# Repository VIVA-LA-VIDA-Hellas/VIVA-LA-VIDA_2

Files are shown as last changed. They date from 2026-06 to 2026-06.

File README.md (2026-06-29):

# **VIVA ΛA VIΔA** 
# $${\color{green}FUTURE \space ENGINEERS \space 2025}$$ 
> ## HELLENIC TEAM

viva la vida gif

## <ins>*Find us on:*<ins/>
Website (https://www.viva-la-vida.gr/)
Youtube (https://www.youtube.com/@VIVALAVIDAFutureEnginners)
Facebook (https://www.facebook.com/groups/1252558666360750)
Instagram (https://www.instagram.com/viva_la_vida_gr/)
TikTok (https://www.tiktok.com/@viva_la_vida_gr)

## TEAM MEMBERS:
### Giannis Kapanikis (user: Dante1307)
### Panagiotis Mourmouris (user: Panos1431)
### Thanos Karatsis (user: thkaratsis)

# INDEX
### *Use the index for an easy navigation of our github or, continue bellow to view our creation process, as well as an overview on everything about the robot.*

## 1. Mobility management
####        1.1 [Motor](schemes/Mechanical_Parts/Motor)
####        1.2 [Ackerman](schemes/Mechanical_Parts/Ackermann)
####        1.3 [Servo](schemes/Mechanical_Parts/Servo)
####        1.4 [Servo and motor 3d Bases](models/3d_designs)

## 2. Power Management
####        2.1 [PCB circuit designs and schematics](schemes/PCB_Design)

## 3. Sensors
####        2.1 [Distance sensors](schemes/Sensors/Distance_Sensors)
####        2.2 [Accelerometre / Gyro](schemes/Sensors/Accelerometre_Gyro)
####        2.3 [Camera](schemes/Sensors/Camera)
####        2.4 [Buttons & Leds](schemes/Sensors/Buttons_Leds)

## 4. 3D Prints
####        4.1 [3D schematics](models/3d_designs)

## 5. Pictures 
####        5.1 [Team photos](t-photos)
####        5.2 [Vehicle photographs](v-photos)

## 6. Performance videos
####        6.1 [Youtube channel link](https://www.youtube.com/@VIVALAVIDAFutureEnginners)
####        6.2 [All video links](video)

## 7. Code files
####        8.1 [Open Challenge](src/1.Open_Challenge)
####        8.2 [Obstacle Challenge](src/2.Obstacle_Challenge)
####        8.3 [Colour Calibration](other/python_files/Color_Picker.py)

## 8. Manuals
####        9.1 [Instruction manuals](schemes/instructions)
####        9.2 [Lego ackerman instructions](schemes/instructions/lego_ackermann_instructions.md)
####        9.3 [Lego differential instructions](schemes/instructions/lego_differential_instructions.md)
####        9.4 [Build details](v-photos)
####        9.5 [Full instructions](schemes/instructions/Instruction_manuals.md)

## 9. Extra material
####        10.1 [Team logo](https://github.com/VIVA-LA-VIDA-Hellas/VIVA-LA-VIDA/tree/main/Team%20-%20Extras/Logo)
####        10.2 [Team name - VIVA ΛΑ VIΔΑ](https://github.com/VIVA-LA-VIDA-Hellas/VIVA-LA-VIDA/tree/main/Team%20-%20Extras/Name)
####        10.3 [Team shirts](https://github.com/VIVA-LA-VIDA-Hellas/VIVA-LA-VIDA/tree/main/Team%20-%20Extras/Shirts)

# RESEARCH / EXPERIMENTAL PHASE

### Creating [red/green colour detection](https://github.com/VIVA-LA-VIDA-Hellas/VIVA-LA-VIDA/blob/main/Code%20files/Python%20files/R_G_cannyoutlineWORKING.py)
Using python and opencv we created a program that detects red and green objects and outputs what the computer sees in the prossess.
To do this, firstly we used colour dropping to <ins> find approximate HSV values  of obstacles and edit the ranges in our code </ins>

### $${\color{red}Red:}$$



### $${\color{green}Green:}$$



### [Colour picker used](https://pinetools.com/image-color-picker)

Using the data, we created a range where an object is detected as red or green. The full range that can be detected is min:0 , max:255
```python
    red_lower = np.array([0, 120, 70])
    red_upper = np.array([10, 255, 255])
```
```python
    green_lower = np.array([45, 160, 0])
    green_upper = np.array([100, 255, 150])
```
Then, we applied a HSV mask to separate the objects of each colour from the rest of the feed and used imgcanny to find the corners of the objects detected, using that to add an outline according to their colour (red/green)
Mask:
```python
mask_red1 = cv2.inRange(imgHSV, red_lower, red_upper)
```
Outline:
```python
    img_contours = img.copy()
    for contour in contours_red:
        x, y, w, h = cv2.boundingRect(contour)
        cv2.rectangle(img_contours, (x, y), (x + w, y + h), (0, 0, 255), 2)  # Red rectangle
```
Same for green.
> ### Green:


> ### Red:



Notice how it even detects the pile of red objects on the floor **~3m away**, We want to turn based on the closest object to the robot at any given time.
To detect that, we add limits to the size we consider an object 
> We do this so that it doesnt start turning too early or if it sees a spec of green/red in the background), its basically a filtering process that cuts down on most of the >noise.

For trials we set the minimum requirement in size (area) for a detected colour mass to be considered an object, as **500 pixels**
```python
def get_largest_contour(mask, min_area=500)
```

Next, we made it choose the largest object visible to focus on first
```python
def get_largest_contour(mask, min_area=500):
    contours, _ = cv2.findContours(mask, cv2.RETR_EXTERNAL, cv2.CHAIN_APPROX_SIMPLE)
    if not contours: return None
    largest = max(contours, key=cv2.contourArea)
    if cv2.contourArea(largest) < min_area: return None
    x, y, w, h = cv2.boundingRect(largest)
    return largest, (x, y), (x + w, y + h), w*h
```

### Updating our colour picking method
The issue with this code was that it needed calibrating in different lighting conditions, so we made out own [colour picker](https://github.com/VIVA-LA-VIDA-Hellas/VIVA-LA-VIDA/blob/main/Code%20files/Python%20files/New%20files%20September%2B/Colour_picker.py) that worked more accurately with the hsv values our camera detected. With this the obstacle detection became much more time efficient but also accurate.

Colour picker sample
```python
def mouse_callback(event, x, y, flags, param):
    global frame
    if event == cv2.EVENT_LBUTTONDOWN and frame is not None:
        bgr = frame[y, x]
        hsv = cv2.cvtColor(np.uint8([[bgr]]), cv2.COLOR_BGR2HSV)[0][0]
        print(f"Clicked at ({x},{y}) | BGR: {bgr} | HSV: {hsv}")

cv2.namedWindow("Live Feed")
cv2.setMouseCallback("Live Feed", mouse_callback)
```
We use input from our camera to our computer as a live feed, clicking on any pixel to get the HSV values the camera detects straight to our terminal.
We can then imput them straight into our colour detection limits, (red_lower, red_upper, green_lower, green_upper)

### Using what we detected to avoid the obstacles
Now that we can succesfully detect the red and green obstacles, we decided to implement a simple system for the robot to use in order to turn. 
It uses the Objects detected as a reference point and tries to rotate away from them, untill they are outside of the visible area (in other words, when they are far away enough for the robot to not collide with them).
Reminder, the robot must move **right** if it detects **red** and on the flip side, **left** when it detects **green**
> In other words, if we draw a line on the right side of the "turn right" block (red) and the left side of the "turn left" block (green), by moving toward the side it is placed on and effectively moving the entire obstacle out of our view, we manage to pass it.

So for **Green** (Turn left):

green pillar

And for **Right** (Turn right):

red pillar

### Next, we created the [Middle_Lane_Canny](https://github.com/VIVA-LA-VIDA-Hellas/VIVA-LA-VIDA/blob/main/Code%20files/Python%20files/Middle_Lane_Canny_WORKING.py)
We applied the same code from the previous program, this time switching green and red with white and black in order to diffrentiate the (white) floor from the (black) walls.
From this process, instead of outlining the walls found, we used the line they formed from edge detection on each side and <ins> calculated the middle point between the two to create a path for the robot to follow </ins>
```python
for i in range(height):
        left_avg = left_edges[i]
        right_avg = right_edges[i]

        if left_avg is not None and right_avg is not None:
            # Calculate the midpoint and draw the path
            middle_line = (left_avg + right_avg) // 2

            # Draw the path line (white) with increased thickness
            cv2.line(edges_black, (middle_line, i), (middle_line, i), (255, 255, 255), 3)  # Increased thickness
```

[You can see the output we got here](https://github.com/VIVA-LA-VIDA-Hellas/VIVA-LA-VIDA/blob/main/Videos/MIDDLE_LANE_VIDEO_COMPRESSED.mp4)

### Output image

### When we moved the inner square walls, <ins>the path to follow (middle lane) moved too</ins>


### Why we didn't end up using this code (Middle_Lane_Canny) for the first mission
Although this code worked exceptionally well when the robot was faced with long straight paths surrounded by contrasting walls, the same can't be said for turns.
When we tested it with a large camera connected to a laptop, it was facing the track from a very high up angle so it had a better view and could detect turns well.
But, when we tested multiple different cameras connected to a raspberry pi, including a fisheye camera, none of them has a scope wide enough for the current code to predict sharp turns, so the path ended up either guiding the robot straight into the wall, or, turning the opposite direction than expected.  

This wasnt working for us. The camera couldn't be as high up as it was originally when its placed on the robot -in the track- and it also needed the robot to go relatively slow so it can catch up with the camera feedback. This is fine for the second mission, where obstacle avoidance is a higher priority than speed, but for a quick first mission we had to find a new way to sense when and how much the car needs to turn.

>[!NOTE]
>The fact that this detection process didn't work for us doesn't render it unuseable. Combined with the use of a different logic specifically for turns, there is potential for a useable output but we decided to take a different approach.

### Recognising turns - Detecting Blue and Orange lines
Using the same colour picking process we created earlier, we can also detect blue and orange. Using these colours we were able to turn as well as the direction of said turn.

Example values:
## $${\color{blue}Blue}$$
```python
    blue_lower = np.array([100, 60, 80])
    blue_upper = np.array([120, 120, 170])
    mask_blue = cv2.inRange(imgHSV, blue_lower, blue_upper)
```
## $${\color{orange}Orange}$$
```python
    orange_lower = np.array([0, 110, 110])
    orange_upper = np.array([20, 160, 230])
    mask_orange = cv2.inRange(imgHSV, orange_lower, orange_upper)
```

Of course, these values have to be calibrated before the launch of every mission due to the changes in lighting conditions, but we found that this process was much more failproof so it was utilised for the second mission.

The logic of the [Blue and Orange turn detection](https://github.com/VIVA-LA-VIDA-Hellas/VIVA-LA-VIDA/blob/main/Code%20files/Python%20files/New%20files%20September%2B/Stage%202/Orange%20Blue%20detection.py) Program is as follows:

Using the HSV mask, this time with blue and orange instead of red and green, we detect the presense of those colours in the feed.
The difference between the detection comes with the shape of what we're trying to detect. Instead of the cube shaped obstacles that were being previously detected as squares, we needed to now detect lines - continuous strings of pixels with either colour.

 We detected the lines using Hough Transform
 ```python
    lines_orange = cv2.HoughLinesP(edges_orange, 1, np.pi / 180, threshold=50, minLineLength=50, maxLineGap=10)
    lines_blue = cv2.HoughLinesP(edges_blue, 1, np.pi / 180, threshold=50, minLineLength=50, maxLineGap=10)

    img_lines = img.copy()

    # Draw lines for visualization
    if lines_orange is not None:
        for x1, y1, x2, y2 in lines_orange[:, 0]:
            cv2.line(img_lines, (x1, y1), (x2, y2), (255, 0, 0), 2)

    if lines_blue is not None:
        for x1, y1, x2, y2 in lines_blue[:, 0]:
            cv2.line(img_lines, (x1, y1), (x2, y2), (0, 165, 255), 2)
 ```
We needed to track which of the two lines (If they were visible) was closest to the robot.
Since the camera output is in 2d, the **depth** that we see is changed into **height**.

<p align="center" width="100%">
    From our angle vs from the robots point of view: 
</p>
<p align="center" width="100%">
     
     
</p>

<p align="center" width="100%">
    From the robot's perpective, the line that is closer to it is also <ins> the line that appears lower on its y axis. </ins>
     
</p>

As you can see in the above image, in this specific scenario where the orange line is clearly closer than the blue one, it is also lower at the point where it intersects with the y axis.
We utilised this property in our code, but instead of using the point y=0 (midpoint) as reference, we used the pixels of our camera output.
Since when we start out camera configuration, we always set it to:

```python
picam2 = Picamera2()
picam2.configure(picam2.create_preview_configuration(main={"size": (640, 480)}))
picam2.start()  
```
So, a total of 640 pixels on the y axis and 480 on the x axis,
>[!NOTE]
>The values start at the top-left most corner where (x,y) is (0,0), Therefore when an object is detected at (example) (x,600), it is at the bottom of the screen.
>Since we want the object to be close to the robot when it turns to avoid turning too early, we set a reference point of y=400 to act as a "secondary x axis", where if orange/blue is detected above that limit (so, on the lower third of the screen), the car should turn.

For safety, we also implemented a condition to eliminate the chanse of both a orange and blue line simulatiously being found bellow the threshold, where the robot only takes into account the one which is closest to itself.

```python
        orange_y = 0
        blue_y = 0
        orange_y = y_at_center(lines_orange)
        blue_y = y_at_center(lines_blue)
 ```

*The values of orange_y and blue_y are originally set to 0 to avoid an error we encountered where the lower line was detected bellow the threshold before the further one was detected at all, returning a non valid value ("NONE") and ending the program abruptly.

```python
        if orange_y > blue_y and orange_y > 400:
            print("Turn right (orange line lower at center)")
            Turn = "Right"
            TURN_ANGLE = 120
        elif blue_y > orange_y and blue_y > 400:
            print("Turn left (blue line lower at center)")
            Turn = "Left"
            TURN_ANGLE = 60
        else:
            print("No line detected at center")
            Turn = "No"
```

Using the above logic combined with an IMU for turning, we managed to make our [imucameraturn.py](https://github.com/VIVA-LA-VIDA-Hellas/VIVA-LA-VIDA/blob/main/Code%20files/Python%20files/New%20files%20September%2B/Stage%202/imucameraturn.py) program.
> ## A program that:
> Moves forward until either a blue or orange line is detected
> Depending on which one is a) lower and b) bellow our set threshold of 400 pixels, output the turn direction (left or right)
> Steer untill the IMU detects the 90 degree change, by setting the servo angle to point left or right accordingly.

This straight-forward logic was ready to be implemented in the trials for the **second mission.**

# First mission - Final programm description

<!-- TOC -->
- [Project Overview](#project-overview)
- [Core Functionality](#core-functionality)
- [Control Logic (high level)](#control-logic-high-level)
- [Code Structure](#code-structure)
- [Hardware Setup](#hardware-setup)
- [Configuration](#configuration)
- [System Architecture Diagram](#system-architecture-diagram)
- [Mission Path Diagram](#mission-path-diagram)
<!-- /TOC -->

The program runs on a **Raspberry Pi** and offers two operation modes:
- **GUI Mode (Debug):** Visual interface with real-time plots and tuning sliders.
- **Headless Mode (Competition):** Fully autonomous execution via physical start button.

---

## Core Functionality 
- **Autonomous Navigation:**
  - Follows walls using ToF (VL53L0X) or Ultrasonic sensors.
  - Performs left/right turns based on open-space detection and front thresholds.

- **Finite-State Machine Logic:**
  - Operates under these main states:  
    `IDLE → CRUISE → TURN_INIT → TURNING → POST_TURN → STOPPED`
  - Each state manages specific motor and servo behaviors.

- **Sensor Fusion & Filtering:**
  - Combines ToF/ultrasonic inputs using median, spike rejection, and optional EMA smoothing.
  - Stabilizes readings and eliminates transient noise.

- **Yaw & Turn Control:**
  - Integrates MPU6050 gyro data for angular tracking.
  - Executes precision turns with direction locking, timeouts, and slew-limited servo control.

- **Adaptive Environment Handling:**
  - Detects narrow corridors via side-sum analysis.
  - Dynamically scales speed and correction margins for safer movement.

- **Safety & Lap Control:**
  - Instant front-stop and obstacle recheck timer.
  - Lap counting with automatic halt after the final lap.

---

## Control Logic (high level) 
- **CRUISE:** Straight motion; after 1st turn, apply timed wall-following corrections if side distance < soft margin.
- **TURN_INIT:** When `front < FRONT_TURN_TRIGGER` and lockout OK; keep straight (or gentle correction after 1st turn) while waiting for **exactly one** open side. Apply optional **direction lock** after the first decision.
- **TURNING:** Set servo to the commanded (left/right) angle; integrate gyro Z and **stop when target yaw** is reached within tolerance. Guards: timeout and max yaw.
- **POST_TURN:** Short straight stretch to stabilize, then return to CRUISE.
- **STOPPED:** Triggered by obstacle or max-laps; obstacle mode self‑retries after a wait window.

**Narrow Mode:** If `left+right` (valid readings) < threshold, scale speeds/thresholds to be conservative in tight corridors.

---

## Code Structure 

1. Imports
    - External Libraries
    - Internal Modules
2. Variables
    - Global Constants
    - Robot-Specific Variables
3. H/W Setup
    - Hardware Configuration
    - Pin Assignments
4. Robot Classes
    - Sensor Handling
    - Motor Control
    - State Management
5. Robot Loop
    - Main Control Loop
    - Decision Making
    - Movement Logic
6. GUI
    - Tkinter Setup
    - Sliders & Data Visualization
7. Main
    - Initialization
    - Robot Execution
      
---

## Hardware Setup 
| Component | Function |
|---|---|
| Raspberry Pi | Core computing unit |
| PCA9685 | Motor and servo PWM driver |
| VL53L0X ToF Sensors | Distance measurement |
| Ultrasonic Sensors | Alternative wall sensing |
| MPU6050 | Gyro for yaw tracking |
| LEDs | Status indication |
| Button | Start trigger in headless mode |

---

## Configuration 
Configuration values are defined in code but can be overridden using `1st_mission_variables.json`.
All GUI slider changes can be saved and reloaded.

---

## System Architecture Diagram 
```text
 ┌──────────────────────────────────────────┐
 │             SENSOR THREAD                │
 │  - ToF & Ultrasonic readings             │
 │  - Median & EMA filtering                │
 │  - Updates global sensor_data            │
 └──────────────────────────────────────────┘
                    │
                    ▼
 ┌──────────────────────────────────────────┐
 │            ROBOT LOOP (FSM)              │
 │  IDLE → CRUISE → TURN_INIT → TURNING →   │
 │  POST_TURN → STOPPED                     │
 │  - Yaw integration (MPU6050)             │
 │  - Servo & motor control                 │
 │  - Lap counting & safety                 │
 └──────────────────────────────────────────┘
                    │
                    ▼
 ┌──────────────────────────────────────────┐
 │             GUI / HEADLESS MODE          │
 │  - Dashboard                             │
 │  - Sliders, plots, and CSV export        │
 │  - Physical start button (headless)      │
 └──────────────────────────────────────────┘
```

---

## Run Modes 
- **Debugging (GUI) Mode:**
  Set `USE_GUI = 1` and press Start Readings & Start Loop button.
- **Competition (Headless) Mode:**
  Set `USE_GUI = 0` and press the hardware start button.

---

# BOM Bill of materials all prices for our robot compartments

## Core System
| Material | Amount | Price  |
|---|---|---|
| Raspberry Pi 5 8GB | 1 | 96.50 |
| Raspberry Pi Micro SD 64GB | 1 | 9.50  |
| Active Cooler for Raspberry Pi 5 | 1 | 6.40  |
| GPIO Ribbon Cable 40P | 1 | 2.00  |
| IDC Connector 2x20 Pin Male | 1 | 0.45  |

## Sensors
| Material | Amount | Price |
|---|---|---|
| Camera Arducam IMX219 fisheye lens | 1 | 18.92 |
| Ultrasonic Sensor HC-SR04 | 3 | 5.40  |
| Laser Sensor - VL53L0X | 6 | 28.80 |
| Triple Axis Gyroscope & Accelerometer MPU6050 | 1 | 3.60  |

## Power & Protection
| Material | Amount | Price |
|---|---|---|
| Battery Holder 1x18650 for PCB | 3 | 2.70  |
| Battery Lithium 18650 3.6V 3400mAh | 3 | 17.40 |
| Li-ion Battery Charger Protection Board | 1 | 3.40  |
| Fuse 4A | 1 | 0.71  |
| Main Power Switch | 1 | 2.23  |
| DC Power Jack 5.5×2.1mm | 1 | 0.20  |
| Step-Down Converter LM2596S | 1 | 2.90  |

## Motors & Motion
| Material | Amount | Price |
|---|---|---|
| Metal Gearmotor 25mm – 210RPM 9–12V | 1 | 6.80  |
| DC Motor Driver Board DRV8871 | 1 | 10.80 |
| Standard Servo MG996R | 1 | 8.90  |
| 16-Channel PWM/Servo Driver PCA9685 | 1 | 6.80  |

## Wiring & Connectors
| Material | Amount | Price |
|---|---|---|
| Jumper Wires 30cm 5-Pin | 6 | 2.50  |
| Molex KF2510 Jumper Wire 4-Pin | 3 | 1.20  |
| Flexible Flat Cable 0.5mm 22-Pin | 1 | 2.90  |

## PCB & Prototyping
| Material | Amount | Price |
|---|---|---|
| PCB Prototype | 5 | 26.25 |
| Tact Switch SMD | 1 | 0.08  |
| LED 0805 SMD | 3 | 0.36  |
| Resistor 0805 | 12 | 0.24  |

## Fasteners & Hardware
| Material | Amount | Price |
|---|---|---|
| M2 Plastic F/F L20mm | 2 | 0.30  |
| M2×8mm | 8 | 0.47  |
| M3×12mm Flat Head | 2 | 0.11  |
| M3×16mm Flat Head | 20 | 1.15  |
| M3×20mm Flat Head | 14 | 0.97  |
| M3×30mm Flat Head | 2 | 0.15  |
| M3×50mm | 2 | 0.70  |

##  [Complete list of all materials amounts and prices](https://github.com/VIVA-LA-VIDA-Hellas/VIVA-LA-VIDA/blob/main/Instruction%20Manuals/Materials%20needed%20and%20BOM.md)

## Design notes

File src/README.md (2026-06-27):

# This directory includes the code needed to complete two missions, the open challenge and the obstacle challenge, as well as the requirements to run the code itself 

## Open Challenge Requirements And Code

### Libraries:
numpy, 
gpiozero, 
lgpio, 
adafruit-circuitpython-pca9685, 
adafruit-circuitpython-mpu6050, 
adafruit-circuitpython-vl53l0x, 
adafruit-blinka, 
matplotlib
### Code:
[Open Challenge Code](1.Open_Challenge/Open_Challenge.py)

## Obstacle Challenge Requirements And Code 

### Libraries:
OpenCV (cv2), 
NumPy, 
Picamera2, 
smbus2, 
gpiozero, 
lgpio, 
adafruit-blinka, 
adafruit-circuitpython-vl53l0x

### Code:
[Obstacle Challenge Code](2.Obstacle_Challenge/Obstacle_Challenge.py)

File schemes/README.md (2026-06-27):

### This directory consists of the electromechanical components used for this project, as well as further information about them such as, justification of use, component characteristics, assembly manuals and discriptive photos explaining the different parts of the PCB placket utilized 

## Mechanical Components (motor, servo, ackermann...)
 - [Motor](Mechanical_Parts/Motor)
 - [Servo](Mechanical_Parts/Servo)
 - [Ackermann](Mechanical_Parts/Ackermann)
 - [Differential](Mechanical_Parts/Differential)
 - [Block_Diagram](Mechanical_Parts/Block_Diagram)
## Discriptive PCB Photos
### Top


### Bottom


## Final PCB design layout 

### Top and bottom compartments of the PCB
top side PCB
bottom pcb

### Top layer
red seperate (top) PCB

### Bottom layer
blue bottom silk layer PCB

### Combined top and bottom layer
PCB Mixed top and bottom

## PCB Render 3D/2D
### 3D
Front


Back


### 2D


## Assembly Manuals
- [Vehicle](instructions/Instruction_manuals.md)
- [Ackermann](instructions/lego_ackermann_instructions.md)
- [Differential](instructions/lego_differential_instructions.md)

>  [!NOTE]
>  These designs were created entirely by us with the use of EasyEDA.
>  [Click here to go to their website and find out more](https://easyeda.com/)

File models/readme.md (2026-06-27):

## Here you can find the files of our 3D print designs, download them and import them to your selected software to print
1. Camera Base
   - [Camera Base](3d_designs/VLV-camerabase-final.stl)

2. Chassis Model
   - [Chassis](3d_designs/VLV-chassis-final.stl)

3. Distance Sensor Base
   - [Distance Sensor Base](3d_designs/VLV-disensorbase-final.stl)

4. Motor Base
   - [Motor Base](3d_designs/VLV-motorbase-final.stl)

5. Motor Gear
   - [Motor Gear](3d_designs/VLV-motorgear-final.stl)

6. Servo Holder
   - [Servo Holder](3d_designs/VLV-servoholder-final.stl)

7. ToF Base
   - [Time of Flight Base](3d_designs/VLV-Tof-final.stl)

## What follows are the LEGO pieces required to build the same differential gear and ackerman system as ours

### Differential Pieces
- [LEGO Differential Pieces](LEGO_parts/Differential/)

### Ackermann Pieces
- [LEGO Ackermann Pieces](LEGO_parts/Ackermann/)

> ### If you want to use the same software we did, check out [Fusion 360](https://www.autodesk.com/products/fusion-360/overviewhttps://www.autodesk.com/products/fusion-360/overview)

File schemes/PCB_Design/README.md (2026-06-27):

## Discriptive PCB photos



## PCB Compartments
### Top

### Bottom


## PCB Layers
### Top

### Bottom

### Combined


## PCB Render 3D/2D
### 3D
Front


Back


### 2D


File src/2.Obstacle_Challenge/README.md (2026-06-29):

## Viva La Vida — WRO FE Obstacle Challenge 

## **VIVA ΛA VIΔΑ** 

IN A ROBOTICS/ENGINEERING CONTEXT, IT IS A FUN, PLAYFUL SLOGAN MEANING “LONG LIVE THE SCREW!”, CELEBRATING THE SIMPLE BUT ESSENTIAL MECHANICAL COMPONENT! 

VivaLaVida WRO 2025 Future Engineers 2[nd] Mission (Obstacle Challenge) 

## **Table of Contents** 

|1|Overview & Scope .............................................................................................................................. 1|
|---|---|
|2|The robot - Hardware & Wiring ......................................................................................................... 2|
|3|System Architecture .......................................................................................................................... 3|
|4|Decision‑Making Architecture .......................................................................................................... 6|
|5|Finite State Machine (FSM) .............................................................................................................. 8|
|6|Diagrams .......................................................................................................................................... 10|
|7|Appendix A - Variables .................................................................................................................... 11|

Technical Design & Validation Report 

VivaLaVida WRO 2025 Future Engineers 2[nd] Mission (Obstacle Challenge) 

## **1 Overview & Scope** 

Mission: Autonomously complete three (3) laps on the official Obstacle Challenge track while respecting randomly placed red and green traffic signs and finishing with a parallel parking manoeuvre inside the parking lot. The robot must decide on which side of the lane to drive based on the colour of the pillars and must avoid moving them. After three laps, it has to locate the magenta parking lot and perform a controlled parallel park. 

The game field is a fixed-width racetrack divided into straight sections and corners. At predefined “seats” along the straights, red or green traffic signs (50×50×100 mm pillars) can be placed before each round. A red pillar instructs the vehicle to keep to the right side of the lane, while a green pillar instructs it to keep to the left side. The vehicle must not knock over, push, or significantly displace these signs during its run. 

After the third lap, the objective changes from lap-time to precision: the robot needs to detect the magenta parking lot limitations and execute a parallel parking manoeuvre so that the car is fully inside the parking area and aligned with the parking borders. 

Our solution reuses the same core hardware platform as in the 1st mission (Raspberry Pi, IMU, ultrasonic/ToF distance sensors, steering servo, DC motor), but adds a camera-based perception pipeline. Computer vision is responsible for lane and traffic-sign detection; the distance sensors and IMU provide safety, collision avoidance, and yaw-based heading control. A finite state machine (FSM) coordinates all behaviours: lap driving, sign handling, obstacle avoidance, parking search, and the parking manoeuvre itself. 

Technical Design & Validation Report - 1 

VivaLaVida WRO 2025 Future Engineers 2[nd] Mission (Obstacle Challenge) 

## **2 The robot - Hardware & Wiring** 

## **2.1 Bill of Materials** 

|**Component**<br>**Role**<br>**Interface/Notes**|**Component**<br>**Role**<br>**Interface/Notes**|**Component**<br>**Role**<br>**Interface/Notes**|
|---|---|---|
|**Raspberry Pi**|Main controller|GPIO/I²C|
|**PCA9685**|Servo + motor PWM|50 Hz PWM; I²C|
|**MPU6050**|Gyro-Z for yaw|I²C|
|**Ultrasonic x3**|Front/Left/Right|Trig/Echo via gpiozero|
|**VL53L0X (opt.)**<br>~~a~~|ToF sensors|I²C + XSHUT addressing|
|**Steering Servo**<br>~~a~~|Single|1000–2000 µs pulse|
|**Motor + Driver/ESC**|Single|PWM ch1/ch2 (FWD/REV)|
|**Start Button**|Headless start|GPIO20|
|**Status LEDs**|Green / Red|GPIO19 / GPIO13|
|**Battery/Power**|5–6 V servo; 5 V logic|Common ground|

## **2.2 Pin Map** 

|**Subsystem**<br>**Signal**<br>**Pin/Channel**<br>**Dir**<br>**Notes**|**Subsystem**<br>**Signal**<br>**Pin/Channel**<br>**Dir**<br>**Notes**|**Subsystem**<br>**Signal**<br>**Pin/Channel**<br>**Dir**<br>**Notes**|**Subsystem**<br>**Signal**<br>**Pin/Channel**<br>**Dir**<br>**Notes**|**Subsystem**<br>**Signal**<br>**Pin/Channel**<br>**Dir**<br>**Notes**|
|---|---|---|---|---|
|**Start Button**<br>~~kk~~|START_BTN<br>~~#4«£~~|GPIO 20|IN|Pull-up; active LOW|
|**LEDs**<br>~~kk~~|GREEN/RED<br>~~#4«£~~|GPIO 19 / 13|OUT|Status/ready|
|**US Front**<br>~~kk~~<br>~~a~~|TRIG / ECHO<br>~~#4«£~~<br>~~a~~|22 / 23<br>~~=~~|OUT / IN<br>~~=~~|max_distance, queue_len<br>~~=~~|
|**US Left**<br>~~a~~|TRIG / ECHO<br>~~a~~|27 / 17<br>~~=~~|OUT / IN<br>~~=~~|max_distance, queue_len<br>~~=~~|
|**US Right**<br>~~a~~|TRIG / ECHO<br>~~a~~|5 / 6<br>~~=~~|OUT / IN<br>~~=~~|max_distance, queue_len<br>~~=~~|
|**Servo**<br>~~a~~|SERVO_CHANNEL<br>~~a~~|PCA ch 0<br>~~=~~|PWM<br>~~=~~|Steering<br>~~=~~|
|**Motor**<br>~~a~~|MOTOR_FWD /<br>REV<br>~~a~~|PCA ch 1 / 2<br>~~=~~|PWM<br>~~=~~|Duty 0–100%<br>~~=~~|
|**I²C**<br>~~a~~|SCL / SDA<br>~~a~~|board.SCL /<br>board.SDA<br>~~=~~|—<br>~~=~~|PCA/IMU/ToF<br>~~=~~|
|**ToF XSHUT**|L/R/F/B/LF/LR|D16 / D25 / D26 /<br>D24 / D8 / D7|OUT|Addr<br>0x30/31/32/33/34/35|

Technical Design & Validation Report - 2 

VivaLaVida WRO 2025 Future Engineers 2[nd] Mission (Obstacle Challenge) 

## **2.3 Robot photos** 

## **3 System Architecture** 

The Obstacle Challenge solution is implemented as a single Python program running on a Raspberry Pi. It builds on the same electromechanical stack as the 1st mission (PCA9685 for servo/motor PWM, MPU6050 IMU for yaw, ultrasonic/ToF for distances), and extends it with a camera module for lane and traffic-sign detection. 

At a high level, the architecture is divided into three layers: 

## 1. **Perception Layer** 

`o` **Camera & Computer Vision** 

- PiCamera2 captures RGB frames at a fixed resolution and frame rate. 

- OpenCV converts frames to HSV colour space and extracts: 

   - Blue/orange lane markings on the mat. 

   - Red and green traffic signs (pillars). 

   - Magenta parking lot limitations. 

`o` **Range & Pose Sensing** 

▪ Ultrasonic and/or VL53L0X ToF sensors measure front, left, and right distances. 

Technical Design & Validation Report - 3 

VivaLaVida WRO 2025 Future Engineers 2[nd] Mission (Obstacle Challenge) 

▪ An MPU6050 IMU provides gyro-Z data, integrated into **yaw** (relative heading) for turn and heading control. 

## 2. **Decision & Control Layer** 

- A **finite state machine (FSM)** maintains the current high-level mode: 

   - Lap driving (following lane and obeying traffic signs). 

   - Obstacle handling (stop / slow-down in front of unexpected objects). 

   - Parking search (after lap 3). 

   - Parking alignment and execution. 

- The FSM uses: 

   - **Vision features** (lane centre offset, sign type/position, parking markers). 

   - **Distance thresholds** (safety margins and stop distance). 

   - **Yaw targets** (for consistent cornering and straight-line recovery). 

- The controller outputs: 

   - Steering commands (servo angle). 

   - Speed commands (PWM duty to the drive motor). 

## 3. **Infrastructure Layer** 

- **Hardware abstraction** (functions or a small controller class) wraps: 

   - → → 

   - Servo control (angle microsecond pulse PCA9685 duty cycle). 

   - Motor control (forward/backward duty mapping). 

   - Raw sensor reads (ultrasonic, ToF, IMU). 

- **Configuration & logging** 

   - Constants for thresholds and speeds are loaded from code and optional JSON files. 

   - Runtime logs (print statements or optional CSV export) record timestamps, state, yaw, distances, and detection results for offline analysis and tuning. 

I 

n calibration/debug mode, the same program can run with more verbose logging and lower speeds; in competition mode, it uses a fixed configuration and headless start button, respecting the WRO start-up rules (power switch + separate start button). 

## **3.1 Code Structure** 

- **3.1.1 Imports** 

- _**3.1.1.1 External Libraries**_ 

   - cv2, numpy: computer vision (colour conversion, masks, contours, geometry). 

   - picamera2: frame capture from the Raspberry Pi camera. 

   - adafruit_pca9685: PWM driver for motor and steering servo. 

   - adafruit_mpu6050: IMU (gyro-Z readings). 

   - adafruit_vl53l0x and/or gpiozero.DistanceSensor: distance sensors (front, left, right). 

   - threading, time, collections.deque: concurrency and timing. 

- **3.1.2 Global Configuration** 

   - **Camera & vision** 

      - Camera resolution, frame rate, and rotation. 

      - HSV ranges for blue/orange lane lines, red/green traffic signs, and magenta parking markers. 

Technical Design & Validation Report - 4 

VivaLaVida WRO 2025 Future Engineers 2[nd] Mission (Obstacle Challenge) 

   - Cropping percentages (top/bottom/left/right) to restrict processing to relevant regions of interest. 

- **Motion & safety** 

   - Speed setpoints for normal lap driving, sign-approach slowdown, obstacle approach, parking search, and parking manoeuvre. 

   - Distance thresholds for “safe to go”, “slow down”, and “must stop”. 

   - Yaw-related constants for turning and for recovering the straight heading after obstacle avoidance. 

Configuration is initialised with sensible defaults and can optionally be overridden by loading a JSON file so that competition tuning does not require editing the code. 

## **3.1.3 Perception Helpers** 

- **Lane detection** 

   - preprocess_lane(frame): crop, blur, convert to HSV, and threshold for blue/orange. 

   - find_lane_center(mask): compute the lane centre (cx) within a horizontal ROI; return an offset from the image centre. 

## • **Traffic sign detection** 

- detect_signs(frame): threshold for red and green in a near-front ROI, extract contours, filter by area/aspect ratio, and classify each detection as “GREEN_LEFT” or “RED_RIGHT”. 

- The closest valid detection is converted into a discrete **lane side** command that remains active until the next sign. 

## • **Parking detection** 

- detect_parking(frame): search for magenta regions near the right-hand border (or according to starting direction), and output a Boolean “parking_slot_visible” plus approximate geometry. 

## **3.2 Control & FSM** 

- A small enum or set of constants describes the FSM states (e.g. IDLE, LAP_DRIVE, SIGN_HANDLE, OBSTACLE_STOP, PARK_SEARCH, PARK_ALIGN, PARK_EXECUTE, FINISHED). 

- The main loop: 

   1. Grabs a new frame from the camera. 

   2. Reads distance sensors and IMU (gyro-Z). 

   3. Updates yaw by integrating gyro-Z. 

Technical Design & Validation Report - 5 

VivaLaVida WRO 2025 Future Engineers 2[nd] Mission (Obstacle Challenge) 

4. Runs perception helpers to update lane centre, active lane side, sign presence, and parking visibility. 

5. Calls the FSM step function, which decides: 

   - Current speed setpoint. 

   - Steering angle. 

   - State transitions (e.g., after three laps, when a sign is recognised, or when the parking lot comes into view). 

All actuation goes through a small abstraction layer so that the FSM code remains readable and declarative (“set speed to PARK_SLOW”, “steer to lane_center_angle”) rather than dealing directly with PWM counts. 

## **4 Decision‑Making Architecture** 

The decision-making logic separates **perception** , **state-based intent** , and **low-level actuation** . Each step uses explicit thresholds, timeouts, and hysteresis to avoid unstable behaviour. 

## **4.1 Perception Pipeline** 

1. **Lane model** 

   - The bottom part of the image (road near the front of the robot) is cropped and thresholded for blue/orange to obtain a binary mask of lane markings. 

   - The mask is collapsed horizontally to estimate a **lane centre** and its offset relative to the image centre. 

   - This offset is converted into a desired steering angle, with a dead-band around zero to avoid constant micro-corrections. 

## 2. **Traffic sign model** 

- A forward ROI is scanned for red and green blobs with the expected pillar size and aspect ratio. 

- If a green pillar is detected, the robot sets a **mode flag** lane_side = LEFT. If a red pillar is detected, it sets lane_side = RIGHT. 

- Once set, lane_side remains active for the current section until another valid sign is detected, mirroring the rule that signs indicate which side to keep rather than a oneframe command. 

## 3. **Parking lot model** 

- When the “laps completed” condition is satisfied, the perception pipeline starts looking for magenta rectangles corresponding to parking lot limitations. 

Technical Design & Validation Report - 6 

VivaLaVida WRO 2025 Future Engineers 2[nd] Mission (Obstacle Challenge) 

- As the robot approaches, the relative size and position of the magenta blobs are used to align the vehicle beside the slot and to trigger the parking manoeuvre. 

## 4. **Range & heading** 

- Front distance: used to slow down/stop before walls, traffic signs, or unexpected obstacles. 

- Left/right distances: used for additional wall-distance safety and as a fallback estimate when lane markings are momentarily lost. 

- Yaw (integrated gyro-Z): used to stabilise turns, recover original heading after obstacle avoidance, and keep the vehicle aligned during straight segments. 

## **4.2 Behavioural Logic** 

- **Lane following under sign constraints** 

   - The controller computes a **desired lateral offset** based on lane_side: 

      - If lane_side = LEFT, target the left half of the lane. 

      - If lane_side = RIGHT, target the right half of the lane. 

   - The lane-centre offset is combined with this target to produce a steering command. 

   - If lane markings are temporarily lost, the controller falls back to yaw (keep last heading) and side distances (keep a safe margin to the visible wall). 

## • **Obstacle handling** 

- If the front distance falls below a safety threshold, the robot enters an obstacle/stop behaviour: 

   - Speed is ramped down to zero. 

   - The robot waits for a short period and checks again. 

   - If the path becomes clear (e.g., a false positive or transient reflection), the robot resumes lane following. 

   - If the obstacle remains, the FSM may choose a slow “creep” or fail-safe to avoid pushing traffic signs. 

## • **Lap counting** 

- Laps are counted either by yaw-based corner counting (similar to the 1st mission) or by crossing detection of a specific lane pattern near the start section. 

- Once three laps are completed, all sign-based lane decisions are ignored, and the FSM transitions to the **parking phase** , while still maintaining safety distance rules. 

• **Parking** 

Technical Design & Validation Report - 7 

VivaLaVida WRO 2025 Future Engineers 2[nd] Mission (Obstacle Challenge) 

`o` In the parking phase, decisions are dominated by parking-related detections: 

- The robot searches for magenta parking markers. 

- When detected, it aligns longitudinally and laterally using a combination of lane centre, yaw, and distance sensors. 

- The parallel parking manoeuvre is executed as a sequence of controlled reverse/forward segments with predefined steering angles, finalising when the car is inside and aligned. 

All decisions rely on clear numeric thresholds defined in the configuration (e.g. minimum sign area, distance to start slowing, yaw error tolerance). This makes the behaviour reproducible and tunable between rounds. 

## **5 Finite State Machine (FSM)** 

The Obstacle Challenge controller uses a finite state machine to structure behavior into clear phases. Below is a conceptual FSM; the exact constant names in the code can follow this mapping. 

## **5.1 States** 

|**State**<br>**Enter**<br>**Actions**<br>**Exit**|**State**<br>**Enter**<br>**Actions**<br>**Exit**|**State**<br>**Enter**<br>**Actions**<br>**Exit**|**State**<br>**Enter**<br>**Actions**<br>**Exit**|
|---|---|---|---|
|IDLE|Program started;<br>waiting for Start button|Motors off; centre<br>steering; zero lap counter<br>and yaw bias|Start button pressed<br>→ **LAP_DRIVE**|
|LAP_DRIVE|Start pressed; laps < 3|Lane following under<br>currentlane_side; obey<br>sign updates; normal<br>speed|Front too close→<br>**OBSTACLE_STOP**;<br>laps = 3→<br>**PARK_SEARCH**|
|OBSTACLE_STOP|Front distance <<br>STOP_DIST (any time)|Ramp speed to 0; keep<br>heading; wait<br>OBSTACLE_WAIT_TIME<br>and re-check|Path clear→back to<br>previous (usually<br>**LAP_DRIVE**); hard<br>timeout→ **FINISHED**<br>(fail-safe)|
|PARK_SEARCH|Laps completed (≥3)|Ignore new sign<br>instructions; drive slowly;<br>search for parking<br>markers|Parking lot detected<br>→ **PARK_ALIGN**|
|PARK_ALIGN|Parking markers visible|Align alongside slot using<br>lane, magenta markers,<br>yaw, and side distances|Alignment<br>constraints met→<br>**PARK_EXECUTE**|

## **5.2 Sate actions** 

- **IDLE** 

   - On entry: all counters cleared, yaw integration reset, and any sign/lane flags reset. 

Technical Design & Validation Report - 8 

VivaLaVida WRO 2025 Future Engineers 2[nd] Mission (Obstacle Challenge) 

- Guard: only the physical Start button or an explicit software command can leave this state. 

## • **CRUISE** 

- Normal driving mode for the three laps. 

- Uses lane detection plus lane_side (from sign detection) to compute steering. 

- Speeds and accelerations are tuned for lap time while staying safely below distance and yaw limits. 

- Transition to **OBSTACLE_STOP** if d_front < STOP_THRESHOLD. 

- Lap detection increments lap_count; when lap_count >= 3, the state transitions to **PARK_SEARCH** . 

## • **OBSTACLE_AVOID** 

- Purpose: honour the rule that traffic signs must not be pushed or moved. 

- Immediate cut of motor PWM and brake by coasting to stop. 

- Waits for OBSTACLE_WAIT_TIME; if the obstacle is still too close, the robot either remains stopped or executes a very cautious low-speed creep, but never applies enough force to move pillars. 

## • **PARK_SEARCH** 

- Lateral behaviour is simplified (e.g. keep right side of lane, independent of previous sign rules). 

- The vision pipeline prioritises magenta detection; other detections are ignored except for safety. 

- Speed is reduced to improve detection reliability and parking precision. 

## • **PARK_ALIGN** 

- Robot positions itself parallel to the parking slot, at a known offset: 

   - Yaw is corrected so car faces along the lane. 

   - Distance from the parking boundary is adjusted using side sensors. 

- When alignment error (in yaw and lateral distance) is below configurable thresholds, transition to **PARK_EXECUTE** . 

## • **PARK_EXECUTE** 

- Parallel parking sequence: 

   - Reverse with steering into the slot until a distance or time threshold. 

Technical Design & Validation Report - 9 

VivaLaVida WRO 2025 Future Engineers 2[nd] Mission (Obstacle Challenge) 

      - Counter-steer forward slightly to centre the vehicle. 

   - During the manoeuvre, yaw and distances are monitored to avoid collisions with parking boundaries. 

- **FINISHED** 

   - Terminal state for a successful run (three laps + parking). 

   - Motors remain off; the robot awaits manual retrieval or a reset command. 

This FSM keeps the mission logic explicit and easy to explain to judges: every behaviour change is tied to a specific sensor condition or mission milestone (lap count, sign detection, parking detection). 

## **6 Diagrams** 

## **6.1 Pinout / Wiring (Conceptual)** 

Technical Design & Validation Report - 10 

VivaLaVida WRO 2025 Future Engineers 2[nd] Mission (Obstacle Challenge) 

## **7 Appendix A - Variables** 

## **Notes** 

- Units: 

   - Distances in centimetres (cm). 

   - Time in seconds (s). 

   - Angles in degrees (°). 

   - Speeds as 0–100 % motor PWM. 

- Many variables are shared with the 1st mission (speeds, basic safety thresholds, yaw filtering). The 2nd mission adds a new group of **vision-related** and **parking-related** variables. 

Below is a non-exhaustive list of the most important variables grouped by function. 

- **Initialization & Mode** 

- **USE_CAMERA** 

   - Enables/disables the camera and vision pipeline (for testing with only distance sensors). _Values:_ 0 = disabled, 1 = enabled. 

- **START_DIRECTION** 

Encodes whether the run is clockwise or counter-clockwise, affecting lane-side interpretation and parking search direction. 

_Values:_ "CW", "CCW" (or 0/1). 

- **USE_TOF_FRONT / USE_TOF_SIDES** 

Select ToF or ultrasonic sensors for front and side measurements. 

_Values:_ 0 = ultrasonic, 1 = ToF. 

- **Lane & Sign Detection** 

- **HSV_BLUE_LOW/HIGH, HSV_ORANGE_LOW/HIGH** 

HSV ranges used to detect lane markings on the mat (blue and orange lines). 

_Notes:_ Tuned once under competition lighting, kept stable thereafter. 

- **HSV_RED_LOW/HIGH, HSV_GREEN_LOW/HIGH** 

HSV ranges used to detect red and green traffic signs. Based on the official RGB values of the pillars; slightly expanded to allow for lighting changes. 

- **SIGN_MIN_AREA** 

   - Minimum contour area in pixels for a candidate to be considered a valid traffic sign (filters out noise). 

- **SIGN_MAX_ASPECT** 

Maximum allowed width/height ratio to still be considered a “pillar”. Very wide blobs are rejected. 

- **SIGN_PERSIST_FRAMES** 

Number of consecutive frames a detection must appear before lane_side is updated. Helps avoid flicker. 

- **LANE_ROI_TOP, LANE_ROI_BOTTOM (percent)** Vertical cropping percentages (0–1) defining the lane-detection band near the bottom of the image. 

- **LANE_DEAD_BAND** 

Range of lane centre offsets (in pixels or normalised units) considered “good enough” to drive straight. 

- **LANE_KP, LANE_MAX_CORR** Proportional gain and maximum allowed steering correction from lane offset to servo angle. 

- **Parking Detection & Manoeuvre** 

- **HSV_MAGENTA_LOW/HIGH** 

HSV ranges used to detect the magenta parking lot limitations. 

Technical Design & Validation Report - 11 

VivaLaVida WRO 2025 Future Engineers 2[nd] Mission (Obstacle Challenge) 

- **PARK_MIN_AREA** 

Minimum contour area for a magenta region to be treated as a parking marker. 

- **PARK_EDGE_MARGIN** 

How far from the image borders magenta blobs are expected when the robot is correctly aligned with the slot. 

- **PARK_ALIGN_LAT_TOL** Allowed lateral distance error (cm) between the car and the parking boundary before the manoeuvre starts. 

- **PARK_ALIGN_YAW_TOL** 

Allowed yaw error (°) before starting the parallel parking sequence. 

- **PARK_BACK_DIST** , **PARK_FORWARD_DIST** Target reverse and forward travel distances (or equivalent times) during the parking manoeuvre. 

- **PARK_SPEED** 

Speed used during parking; typically much lower than lap speed for precision. 

- **Speeds & Safety (shared with 1st mission, re-used here)** 

- **SPEED_LAP / SPEED_SIGN_APPROACH / SPEED_PARK_SEARCH / SPEED_PARK_EXECUTE** 

Main speed setpoints for each phase of the mission (see Section 6). 

- **STOP_THRESHOLD** 

   - Front distance (cm) below which the robot must stop immediately to avoid collisions or moving traffic signs. 

- **SLOWDOWN_DISTANCE** 

Distance at which the robot starts reducing speed near obstacles or signs. 

- **SIDE_SAFE_DISTANCE** Minimum acceptable distance to side walls or pillars; used as an extra guard when lane information is noisy. 

- **Yaw & Filtering** 

- **YAW_FILTER_ALPHA** 

   - Exponential moving average factor applied to gyro-Z before integration (0–1; higher = less smoothing). 

- **YAW_STRAIGHT_TOL** 

Allowed yaw deviation from the target “straight” heading before corrections are applied. 

- **YAW_PARK_ALIGN_TOL** Stricter yaw tolerance used in the parking alignment phase. 

- **N_READINGS** Window size for median filtering of distance sensors. 

- **FILTER_ALPHA_DIST, FILTER_JUMP_DIST** EMA smoothing factor and maximum jump for distance sensors; large jumps are considered spikes and ignored. 

- **Timing & Mission Management** 

- **OBSTACLE_WAIT_TIME** 

How long to wait in **OBSTACLE_STOP** before re-checking if the path is clear. 

- **FRAME_INTERVAL** 

Desired time between camera processing frames; can be increased to reduce CPU load. 

- **MAX_LAPS** Number of laps to drive before switching to parking logic (3 for the official Obstacle Challenge). 

• **TIMEOUT_PARK_SEARCH** Maximum time allowed in **PARK_SEARCH** before failing safely in **FINISHED** if the slot is never found. 

Technical Design & Validation Report - 12

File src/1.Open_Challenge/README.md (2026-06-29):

## Viva La Vida — WRO FE Open Challenge 

## **VIVA ΛA VIΔΑ** 

IN A ROBOTICS/ENGINEERING CONTEXT, IT IS A FUN, PLAYFUL SLOGAN MEANING “LONG LIVE THE SCREW!”, CELEBRATING THE SIMPLE BUT ESSENTIAL MECHANICAL COMPONENT! 

VivaLaVida 

WRO 2025 Future Engineers 1[st] Mission (Open Challenge) 

## **Table of Contents** 

|1|Overview & Scope .............................................................................................................................. 1|
|---|---|
|2|The robot - Hardware & Wiring ......................................................................................................... 2|
|3|System Architecture .......................................................................................................................... 3|
|4|Decision‑Making Architecture .......................................................................................................... 6|
|5|Finite State Machine (FSM) .............................................................................................................. 8|
|6|Parameters & Profiles ....................................................................................................................... 9|
|7|Diagrams .......................................................................................................................................... 10|
|8|Appendix A - Variables .................................................................................................................... 12|
|9|Appendix B - Source Code Analysis ............................................................................................... 16|
|10|Appendix C - Source code ............................................................................................................... 21|

Technical Design & Validation Report 

VivaLaVida WRO 2025 Future Engineers 1[st] Mission (Open Challenge) 

## **1 Overview & Scope** 

Mission: autonomously complete three laps inside a 3×3 m field containing a randomized 1×1 m inner island that creates corridors. Robot must maintain direction, avoid the walls, and stop safely. Competition rules: single power switch + Start button; no wireless during the run. 

- The robot must autonomously navigate a dynamic track with varying corridor widths, ensuring it avoids walls and stays on course. 

- Key challenges include detecting and responding to obstacles, managing tight turns, and adapting to different track conditions. 

- The robot uses sensors to measure distances and avoid obstacles, with sensor fusion techniques to ensure accurate navigation in real-time. 

Technical Design & Validation Report - 1 

VivaLaVida WRO 2025 Future Engineers 1[st] Mission (Open Challenge) 

## **2 The robot - Hardware & Wiring** 

## **2.1 Bill of Materials** 

|**Component**<br>**Role**<br>**Interface/Notes**|**Component**<br>**Role**<br>**Interface/Notes**|**Component**<br>**Role**<br>**Interface/Notes**|
|---|---|---|
|**Raspberry Pi**|Main controller|GPIO/I²C|
|**PCA9685**|Servo + motor PWM|50 Hz PWM; I²C|
|**MPU6050**|Gyro-Z for yaw|I²C|
|**Ultrasonic x3**|Front/Left/Right|Trig/Echo via gpiozero|
|**VL53L0X (opt.)**<br>~~a~~|ToF sensors|I²C + XSHUT addressing|
|**Steering Servo**<br>~~a~~|Single|1000–2000 µs pulse|
|**Motor + Driver/ESC**|Single|PWM ch1/ch2 (FWD/REV)|
|**Start Button**|Headless start|GPIO20|
|**Status LEDs**|Green / Red|GPIO19 / GPIO13|
|**Battery/Power**|5–6 V servo; 5 V logic|Common ground|

|**Subsystem**<br>**Signal**<br>**Pin/Channel**<br>**Dir**<br>**Notes**|**Subsystem**<br>**Signal**<br>**Pin/Channel**<br>**Dir**<br>**Notes**|**Subsystem**<br>**Signal**<br>**Pin/Channel**<br>**Dir**<br>**Notes**|**Subsystem**<br>**Signal**<br>**Pin/Channel**<br>**Dir**<br>**Notes**|**Subsystem**<br>**Signal**<br>**Pin/Channel**<br>**Dir**<br>**Notes**|
|---|---|---|---|---|
|**Start Button**<br>~~i~~|START_BTN<br>~~4°~~|GPIO 20<br>~~4°~~|IN|Pull-up; active LOW|
|**LEDs**<br>~~i~~|GREEN/RED<br>~~4°~~|GPIO 19 / 13<br>~~4°~~|OUT|Status/ready|
|**US Front**<br>~~i~~<br>~~i~~|TRIG / ECHO<br>~~4°~~<br>~~i~~|22 / 23<br>~~4°~~<br>~~=~~|OUT / IN<br>~~=~~|max_distance, queue_len<br>~~=~~|
|**US Left**<br>~~i~~|TRIG / ECHO<br>~~i~~|27 / 17<br>~~=~~|OUT / IN<br>~~=~~|max_distance, queue_len<br>~~=~~|
|**US Right**<br>~~i~~|TRIG / ECHO<br>~~i~~|5 / 6<br>~~=~~|OUT / IN<br>~~=~~|max_distance, queue_len<br>~~=~~|
|**Servo**<br>~~i~~|SERVO_CHANNEL<br>~~i~~|PCA ch 0<br>~~=~~|PWM<br>~~=~~|Steering<br>~~=~~|
|**Motor**<br>~~i~~|MOTOR_FWD /<br>REV<br>~~i~~|PCA ch 1 / 2<br>~~=~~|PWM<br>~~=~~|Duty 0–100%<br>~~=~~|
|**I²C**<br>~~i~~|SCL / SDA<br>~~i~~|board.SCL /<br>board.SDA<br>~~=~~|—<br>~~=~~|PCA/IMU/ToF<br>~~=~~|
|**ToF XSHUT**|L/R/F/B/LF/LR|D16 / D25 / D26 /<br>D24 / D8 / D7|OUT|Addr<br>0x30/31/32/33/34/35|

Technical Design & Validation Report - 2 

VivaLaVida WRO 2025 Future Engineers 1[st] Mission (Open Challenge) 

## **2.3 Robot photos** 

## **3 System Architecture** 

Code structure: 

- imports & global configuration (speeds, thresholds, filtering, timing); hardware setup (GPIO/I²C, PCA9685, MPU6050, pin constants) 

- 

- 

   - sensor initialization (ToF with XSHUT addressing and ultrasonic fallbacks) 

   - data model & threading primitives (Events, Locks, deques for plotting/logging) 

- RobotController class (low‑level actuation, PWM/servo handling, distance filtering, lane‑keeping corrections, turn‑decision helpers) 

- 

   - sensor_reader thread (continuous filtered measurements into a shared dict) 

- robot_loop FSM (IDLE → CRUISE → TURN_INIT → TURNING → POST_TURN → STOPPED, with yaw integration, narrow‑mode scaling, and safety guards) 

- GUI subsystem (Tkinter plots, status, sliders, CSV export, preset save/load); start/stop handlers; utilities (CSV export, JSON overrides) 

- 

- The __main__ entry (GUI vs headless startup, thread lifecycles, cleanup) 

Technical Design & Validation Report - 3 

VivaLaVida WRO 2025 Future Engineers 1[st] Mission (Open Challenge) 

The stack is organized into two real-time threads plus an optional GUI: 

- sensor_reader: acquires ultrasonic/ToF ranges, applies median+EMA smoothing with spike rejection, and publishes under a Lock. 

- robot_loop: integrates gyro Z to yaw, runs the finite state machine (FSM), computes steering/motor commands via PCA9685. 

- GUI (optional): Tkinter with live plots, tuning sliders, CSV export, and start/stop controls. 

Synchronization uses Events (readings_event, loop_event, sensor_tick) to gate progress without busy-waiting. 

## Outline: 

- Software Workflow: The system operates with a multi-threaded architecture, where sensor readings are continuously acquired and processed, and decisions are made based on these readings. The robot transitions between different states (CRUISE, TURN_INIT, TURNING, STOPPED) based on sensor data and predefined thresholds. 

- Threading: The robot utilizes two main threads: one for acquiring sensor data and another for executing the robot's finite state machine (FSM). This setup ensures real-time performance without busy-waiting, as synchronization is managed using events and locks. 

## **3.1 Code Structure** 

## **3.1.1 Imports** 

## _**3.1.1.1 External Libraries**_ 

Uses standard threading/time/collections plus: gpiozero.DistanceSensor for ultrasounds; Adafruit PCA9685 for PWM (servo & motor); adafruit_mpu6050 for IMU; adafruit_vl53l0x for ToF; Tkinter + matplotlib for GUI/plots; numpy for median/mean; RPi.GPIO for LEDs/button; digitalio + board for XSHUT and I²C lines. These define the runtime I/O model. 

## _**3.1.1.2 Internal Modules**_ 

The solution is a single Python program structured into clear sections (imports, configuration, hardware setup, RobotController class, sensor thread, FSM loop, GUI, utilities, main). No separate packages are required; this keeps deployment simple on the Pi. 

## **3.1.2 Variables** 

## _**3.1.2.1 Global Constants**_ 

Tunable thresholds & timings (e.g., SPEED_* per FSM state; SOFT_MARGIN/MAX_CORRECTION; STOP_THRESHOLD; FRONT_TURN_TRIGGER; TURN_DECISION_THRESHOLD; TURN_TIMEOUT; TURN_LOCKOUT; TARGET_TURN_ANGLE and tolerance; narrow-mode thresholds; filtering alphas/jumps; loop/sensor delays). These drive behavior and can be adjusted via GUI sliders or JSON overrides. 

## _**3.1.2.2 Robot-Specific Variables**_ 

Servo geometry (SERVO_CENTER/MIN/MAX and pulse widths), PCA channels for servo/motor, ultrasonic pins, ToF XSHUT pins, LEDs and Start button. Also stores immutable base values and environment scaling factors (SPEED_ENV_FACTOR, DIST_ENV_FACTOR) used by helper getters 

Technical Design & Validation Report - 4 

VivaLaVida WRO 2025 Future Engineers 1[st] Mission (Open Challenge) 

(eff_*). JSON overrides are loaded by load_variables_from_json() early so all downstream logic sees updated values. 

## **3.1.3 H/W Setup** 

## _**3.1.3.1 Hardware Configuration**_ 

GPIO set to BCM mode; I²C bus initialized. PCA9685 set to 50 Hz (servo-friendly). IMU (MPU6050) instantiated and a 500-sample gyro bias is computed at startup (robot must be still). ToF sensors are optionally addressed via XSHUT (0x30..0x35) and started in continuous mode; fallback to ultrasonic is automatic if ToF init fails. 

## _**3.1.3.2 Pin Assignments**_ 

Front US (TRIG 22 / ECHO 23), Left (27 / 17), Right (5 / 6). Servo on PCA ch 0, motor driver on ch 1/2. Start button on GPIO20 (pull-up, active LOW). LEDs: GREEN 19, RED 13. I²C SCL/SDA. 

## **3.1.4 Robot Classes** 

## _**3.1.4.1 Sensor Handling**_ 

RobotController.filtered_distance() fuses raw ToF/US with a small rolling history (median), jump rejection (FILTER_JUMP[_TOF]) and EMA smoothing (FILTER_ALPHA[_TOF]). Each sensor type uses its own parameters. Distances are normalized to cm; sentinel 999 denotes invalid/unavailable. 

## _**3.1.4.2 Motor Control**_ 

rotate_motor() maps 0–100% duty to PCA9685 channels (FWD/REV). stop_motor() zeros both channels. set_servo() clamps to limits, applies optional slew limiting (SERVO_SLEW_DPS in deg/s) to limit command rate, converts angle to microsecond pulse and to PCA duty cycle. safe_straight_control() produces bounded lane-keeping corrections based on SOFT_MARGIN and MAX_CORRECTION. 

## _**3.1.4.3 State Management**_ 

RobotState enum defines IDLE, CRUISE, TURN_INIT, TURNING, POST_TURN, STOPPED. Events (readings_event, loop_event) gate progression; sensor_tick coordinates waits to keep loops responsive without busy-waiting. Narrow-mode derives from L+R with hysteresis to scale speeds/thresholds. 

## **3.1.5 Robot Loop** 

## _**3.1.5.1 Main Control Loop**_ 

robot_loop() runs continuously after readings_event is set. It integrates yaw from gyro Z (with a simple low-pass) and appends telemetry to deques for plotting. FSM actions drive servo/motor per state with state_speed_value() (affected by narrow-mode scaling). Lap/turn counters update, and POST_LAP behavior enforces stop at MAX_LAPS. 

## _**3.1.5.2 Decision Making**_ 

Turn preconditions: front < FRONT_TURN_TRIGGER and (t − last_turn) ≥ TURN_LOCKOUT. Direction requires XOR (open_left, open_right – only one Input is True), where open is None/999 or > TURN_DECISION_THRESHOLD. Optional LOCK_TURN_DIRECTION fixes the first chosen side. Turn termination uses |Δyaw − TARGET_TURN_ANGLE| ≤ tolerance, else timeout or max-angle as failsafes. STOP_THRESHOLD forces immediate STOPPED with timed auto-retry. 

Technical Design & Validation Report - 5 

VivaLaVida WRO 2025 Future Engineers 1[st] Mission (Open Challenge) 

## _**3.1.5.3 Movement Logic**_ 

Before the first turn, servo stays centered to avoid premature biasing. After the first turn, gentle wallfollowing corrections are applied when a side distance falls below SOFT_MARGIN. POST_TURN holds straight briefly before resuming CRUISE. 

## **3.1.6 GUI** 

## _**3.1.6.1 Tkinter Setup**_ 

launch_gui() builds a 3-panel matplotlib view (front, sides, yaw) with live annotations, start/stop buttons, status indicators (including a circular traffic-light style), and labels for turns/laps. Clean shutdown stops ToF continuous mode and calls several cleanups. 

## _**3.1.6.2 Sliders & Data Visualization**_ 

Grouped sliders expose key parameters (speeds, margins, triggers, timeouts). Changes take effect live and can be saved/loaded as JSON presets. Export CSV captures time series, state, counters, and a snapshot of slider values for later analysis. 

## **3.1.7 Main** 

## _**3.1.7.1 Initialization**_ 

The __main__ guard prints mode and launches GUI or headless path. In headless mode, LEDs indicate readiness; a physical Start press arms readings_event, then loop_event. KeyboardInterrupt and window close handlers stop loops, halt sensors, and clean up GPIO. 

## _**3.1.7.2 Robot Execution**_ 

In GUI mode, sensor and loop threads are started on demand via the buttons. In headless mode, sensor_reader runs as a daemon and robot_loop runs in the foreground after Start. Both modes share exactly the same control logic, ensuring identical behavior during competition. 

## **4 Decision‑Making Architecture** 

The controller separates sensing, eligibility checks, and action commits. Each behavior is guarded by explicit thresholds, hysteresis, and lockouts so that small sensor fluctuations do not cause thrashing. All important decisions are explainable in logs and reproducible by fixed parameter sets (or slider presets). 

## **4.1 Perception Pipeline** 

- Distances are read as meters (gpiozero) or mm (ToF) and normalized to cm. 

- Median over N_READINGS suppresses outliers; EMA (FILTER_ALPHA) smooths; values jumping beyond FILTER_JUMP are rejected. 

- For corridor reasoning we derive: (a) front distance, (b) left & right distances, and (c) left+right sum for narrow-mode. 

Example calibration anchor: with 1.0 m corridor width and a 10 cm robot, left+right is expected near 90 cm; this informs NARROW_SUM_THRESHOLD setting. 

## **4.2 Corridor Model & Narrow‑Mode Scaling** 

We treat the track as four straight corridors and four corners. Narrow‑mode activates when L+R < NARROW_SUM_THRESHOLD and deactivates above threshold+NARROW_HYSTERESIS. When 

Technical Design & Validation Report - 6 

VivaLaVida WRO 2025 Future Engineers 1[st] Mission (Open Challenge) 

active, SPEED_ENV_FACTOR and DIST_ENV_FACTOR can scale state speeds and distance thresholds to keep the robot stable (e.g., drive slower and begin corrections earlier). Hysteresis prevents chatter when moving near the boundary of activation. 

## **4.3 Turn Eligibility (Pre‑conditions)** 

A turn is considered only when (i) the front distance falls below FRONT_TURN_TRIGGER and (ii) the last turn ended ≥ TURN_LOCKOUT seconds ago. This prevents premature or back‑to‑back turns on zig‑zag geometries. 

## **4.4 Direction Selection (Symmetry‑Aware)** 

The side ‘open’ predicate is: distance is None/999 or distance > TURN_DECISION_THRESHOLD. We require XOR (open_left, open_right - only one Input is True) so that we only commit when exactly one side is clearly open; if both are open or both closed we keep waiting in TURN_INIT at a reduced speed. Optionally, LOCK_TURN_DIRECTION fixes the first chosen direction (LEFT/RIGHT) for the session for consistent lap direction. 

## **4.5 Turn Commit & Steering Command** 

Upon selection, we: (a) record yaw_start and time, (b) set the servo to TURN_ANGLE_LEFT/RIGHT (hardware setpoints), and (c) switch to state TURNING with SPEED_TURN. 

## **4.6 Termination Strategy (Multi‑guard)** 

Primary: gyro‑based angle tracking. We estimate Δyaw = yaw − yaw_start and stop when |Δyaw − TARGET_TURN_ANGLE| ≤ TURN_ANGLE_TOLERANCE. Fallback 1: timeout when (now − turn_start) > TURN_TIMEOUT to avoid deadlocks. Fallback 2: a hard cap when |Δyaw| ≥ MAX_TURN_ANGLE to contain extreme cases (e.g., slipping, missing side). After stopping we center the servo, optionally snap yaw to the exact target for continuity, and enter POST_TURN for a short straight stabilization. 

Rationale: IMU bias accumulates slowly, but at corner time‑scales the bias is quasi‑constant; using relative yaw is robust to drift over a single corner. 

## **4.7 Straight‑Line Corrections** 

After the first turn (to establish lane context), wall‑following applies only gentle corrections when min(left,right) < SOFT_MARGIN. The correction magnitude saturates at MAX_CORRECTION; if still near the wall, it can renew. This prevents over‑steering on straights while maintaining a comfortable distance from the inner walls. 

## **4.8 Obstacle Stop & Auto‑Retry** 

If front < STOP_THRESHOLD at any time, motors stop and the state becomes STOPPED with a retry deadline now+OBSTACLE_WAIT_TIME. On expiry the controller rechecks front; if clear (≥ STOP_THRESHOLD) the robot resumes CRUISE. 

## **4.9 Determinism, Hysteresis, and Lockouts** 

- Determinism: state transitions require explicit pre‑conditions and never depend on transient, ambiguous readings. 

- Hysteresis: both narrow‑mode and angle tolerance avoid edge‑case chatter. 

- Lockouts: TURN_LOCKOUT guarantees spacing between turns; servo slew bounds steering rate. 

Technical Design & Validation Report - 7 

VivaLaVida WRO 2025 Future Engineers 1[st] Mission (Open Challenge) 

## **5 Finite State Machine (FSM)** 

**5.1 States** 

|**State**<br>**Enter**<br>**Actions**<br>**Exit**<br>**IDLE**<br>Readings on, loop off<br>Motors off; servo centered<br>Loop on→CRUISE<br>~~ST~~|**State**<br>**Enter**<br>**Actions**<br>**Exit**<br>**IDLE**<br>Readings on, loop off<br>Motors off; servo centered<br>Loop on→CRUISE<br>~~ST~~|**State**<br>**Enter**<br>**Actions**<br>**Exit**<br>**IDLE**<br>Readings on, loop off<br>Motors off; servo centered<br>Loop on→CRUISE<br>~~ST~~|**State**<br>**Enter**<br>**Actions**<br>**Exit**<br>**IDLE**<br>Readings on, loop off<br>Motors off; servo centered<br>Loop on→CRUISE<br>~~ST~~|**State**<br>**Enter**<br>**Actions**<br>**Exit**<br>**IDLE**<br>Readings on, loop off<br>Motors off; servo centered<br>Loop on→CRUISE<br>~~ST~~|**State**<br>**Enter**<br>**Actions**<br>**Exit**<br>**IDLE**<br>Readings on, loop off<br>Motors off; servo centered<br>Loop on→CRUISE<br>~~ST~~|**State**<br>**Enter**<br>**Actions**<br>**Exit**<br>**IDLE**<br>Readings on, loop off<br>Motors off; servo centered<br>Loop on→CRUISE<br>~~ST~~|
|---|---|---|---|---|---|---|
||**CRUISE**||Normal driving|Gentle wall‑following after||Stop→STOPPED;|
|||||1st turn||Turn pre‑conditions→|
|||||||TURN_INIT|
||**TURN_INIT**||Front < trigger & lockout<br>Slow; wait XOR( only one|||Direction chosen→|
||||OK|open side)||TURNING; Front|
|||||||re‑safe→CRUISE|
||**TURNING**||Direction committed|Servo setpoint; track yaw;|Servo setpoint; track yaw;|Angle tolerance OR|
|||||guards||timeout OR max‑angle|
|||||||→POST_TURN|
||**POST_TURN**||Turn finished|Short straight stabilization||Timer elapsed→|
|||||||CRUISE|
|**STOPPED**<br>Obstacle/user/laps<br>Motors off; optional<br>auto‑retry<br>Retry clear→CRUISE<br>~~|Se,~~<br>~~|~~|||||||
|**5.2 Sate actions**|||||||
||**State**||**On-Entry Actions**|**Transition**|**Next State**|**Notes**|
|||||**Condition(guard)**|||
||**START_IDLE**<br>**START_READING**<br>**S**||Motors off; center<br>servo<br>Start sensor thread<br>~~——~~|—<br>—|**START_READ**<br>**INGS**<br>Initial state<br>**CRUISE**<br>—||
||**CRUISE**||Ramp motor; center|front <|**STOPPED**|Safety stop|
||||servo; apply**CRUISE**|STOP_THRESHOLD|||
||||**corrections**(after 1st||||
||||turn) with soft margin||||
||||→||||
||||±MAX_CORRECTION||||
|||||front <|**TURN_INIT**|Prepare to turn|
|||||FRONT_TURN_TRI|||
|||||GGER**AND**|||
|||||lockout_ok|||
|||||(any time) run|**CRUISE**(stay)<br>Detector scales||
|||||**NARROW detector**||speeds/thresholds;|
|||||||not a state change|
||**TURN_INIT**||Slow down; wait|direction_chosen|**TURNING**|If direction locking|
||||XOR(open-side)|||enabled, apply lock|
|||||||now|
||**TURNING**||Servo = target angle;|turn_completed|**POST_TURN**<br>Completion via||
||||monitoryaw|||yaw/angle|
||**POST_TURN**||Short straight|segment_done|**CRUISE**|Re-enter cruise loop|
||||segment||||
||**STOPPED**||Wait window; auto-|retry_window_elap|**CRUISE**|If still blocked after|
||||retry timer|sed**AND**||retries, you may re-|
|||||path_clear||enter STOPPED or|
|||||||fail-safe|

Technical Design & Validation Report - 8 

VivaLaVida WRO 2025 Future Engineers 1[st] Mission (Open Challenge) 

## **6 Parameters & Profiles** 

|**Category**<br>**Key Parameters (defaults)**<br>**Purpose**|**Category**<br>**Key Parameters (defaults)**<br>**Purpose**|**Category**<br>**Key Parameters (defaults)**<br>**Purpose**|
|---|---|---|
|**Speeds**<br>~~~~~|SPEED_CRUISE/TURN_INIT/TURN/POST_TURN|State‑specific duty|
|**Driving**<br>~~~~~<br>~~_—~~|SOFT_MARGIN; CORR_EPS; CORRECTION_MULTIPLIER|Wall‑following|
|**Safety**<br>~~_—~~|STOP_THRESHOLD; TURN_TIMEOUT; TURN_LOCKOUT|Guards|
|**Turns**<br>~~_—~~|FRONT_TURN_TRIGGER; TURN_DECISION_THRESHOLD|Eligibility & direction|
|**Yaw**<br>L<br>||TARGET_TURN_ANGLE; TURN_ANGLE_TOLERANCE;<br>MAX_TURN_ANGLE<br>||Termination|
|**Narrow**<br>~~oo~~|NARROW_SUM_THRESHOLD; NARROW_HYSTERESIS<br>~~oo~~|Scaling & chatter‑free<br>toggling|
|**Filters**|FILTER_ALPHA; FILTER_JUMP; N_READINGS|Smoothing & spike<br>reject|
|**Timing**|LOOP_DELAY; SENSOR_DELAY|Loop pacing|

## **6.1 Preset Profiles** 

|**Profile**<br>**Cruise**<br>**Turn**<br>**Target°**<br>**Tol°**<br>**Front**<br>**Trigger**<br>**Lockout**|**Profile**<br>**Cruise**<br>**Turn**<br>**Target°**<br>**Tol°**<br>**Front**<br>**Trigger**<br>**Lockout**|**Profile**<br>**Cruise**<br>**Turn**<br>**Target°**<br>**Tol°**<br>**Front**<br>**Trigger**<br>**Lockout**|**Profile**<br>**Cruise**<br>**Turn**<br>**Target°**<br>**Tol°**<br>**Front**<br>**Trigger**<br>**Lockout**|**Profile**<br>**Cruise**<br>**Turn**<br>**Target°**<br>**Tol°**<br>**Front**<br>**Trigger**<br>**Lockout**|**Profile**<br>**Cruise**<br>**Turn**<br>**Target°**<br>**Tol°**<br>**Front**<br>**Trigger**<br>**Lockout**|**Profile**<br>**Cruise**<br>**Turn**<br>**Target°**<br>**Tol°**<br>**Front**<br>**Trigger**<br>**Lockout**|
|---|---|---|---|---|---|---|
|**Safe**|20|12|84|6|100 cm|2.0 s|
|**Balanced**<br>**(default)**<br>~~Le~~|25|15|86|5|90 cm<br>~~J~~|1.5 s<br>~~J~~|
|**Aggressive**<br>~~Le~~|40|16|88|4|80 cm<br>~~J~~|1.2 s<br>~~J~~|

## **6.2 Operations Runbook** 

Power → READY LED or GUI → Start Readings → Start Loop (or headless Start). Observe plots; export CSV and save slider presets after runs. 

## **6.3 Boot & Headless Start** 

Boot sequence: RED LED on → sensors init → GREEN LED on blinking (ready). Headless: press Start (GPIO20 goes LOW) to arm readings_event and then loop_event. 

Technical Design & Validation Report - 9 

VivaLaVida WRO 2025 Future Engineers 1[st] Mission (Open Challenge) 

## **7 Diagrams** 

## **7.1 Pinout / Wiring (Conceptual)** 

## **7.2 Driving Area — States** 

Technical Design & Validation Report - 10 

VivaLaVida WRO 2025 Future Engineers 1[st] Mission (Open Challenge) 

## **7.3 Decision Flowchart (FSM + Safety + Narrow Mode)** 

Technical Design & Validation Report - 11 

VivaLaVida WRO 2025 Future Engineers 1[st] Mission (Open Challenge) 

## **8 Appendix A - Variables** 

## **Notes:** 

- Many thresholds are dynamically scaled when the robot enters a narrow corridor. Speeds are multiplied by NARROW_FACTOR_SPEED (via SPEED_ENV_FACTOR) and distance thresholds by NARROW_FACTOR_DIST (via DIST_ENV_FACTOR). The code uses helper functions eff_* to compute effective values. 

- Units: distances in centimeters (cm), time in seconds (s), angles in degrees (°), speeds as 0– 100% PWM. 

## **8.1 Variables** 

|**Variable**<br>**Scope & Detailed Explanation**<br>**Accepted values & meanings **|**Variable**<br>**Scope & Detailed Explanation**<br>**Accepted values & meanings **|**Variable**<br>**Scope & Detailed Explanation**<br>**Accepted values & meanings **|
|---|---|---|
|**— Initialization & Operating**<br>**Mode —**|||
|**USE_GUI**<br>~~——~~|Selects runtime mode. If 1,<br>starts the Tkinter GUI with live<br>plots, sliders, and control<br>buttons. If 0, runs headless<br>and waits for the physical<br>START button(GPIO).<br>~~——~~|0 = headless (competition), 1 =<br>GUI (debug).<br>~~——~~|
|**USE_TOF_SIDES**<br>~~——~~|Chooses sensor type for side<br>distances. 1 initializes<br>VL53L0X ToF for left/right; 0<br>uses ultrasonic.<br>~~——~~|0 = ultrasonic, 1 = ToF<br>(VL53L0X).<br>~~——~~|
|**USE_TOF_FRONT**<br>~~——~~|Chooses sensor type for the<br>front distance sensor.<br>~~——~~|0 = ultrasonic, 1 = ToF<br>(VL53L0X).<br>~~——~~|
|**USE_TOF_CORNERS**<br>~~——~~|Enable or disable corner<br>sensors.<br>~~——~~|0 = disabled, 1 = enabled.<br>~~——~~|
|**— Narrow-Corridor Behavior**<br>**—**<br>~~——~~|~~——~~|~~——~~|
|**NARROW_SUM_THRESHOLD**<br>~~——~~|If (left + right) < threshold→<br>narrow mode ON.<br>~~——~~|cm; typical 40–120.<br>~~——~~|
|**NARROW_HYSTERESIS**|Exit narrow mode only when<br>(left + right) > threshold +<br>hysteresis.|cm; typical 5–30.|
|**NARROW_FACTOR_SPEED**|Multiplier applied to state<br>speeds in narrow mode (via<br>SPEED_ENV_FACTOR).|Float ≥ 0.0; 1.0 = no change.|
|**NARROW_FACTOR_DIST**|Multiplier applied to distance<br>thresholds in narrow mode<br>(via DIST_ENV_FACTOR).|Float ≥ 0.0; 1.0 = no change.|
|**— Speeds(0–100%) —**|||
|**SPEED_IDLE**|Motor command in IDLE.|0–100;usually0.|
|**SPEED_STOPPED**|Motor command in STOPPED.|0–100;usually0.|
|**SPEED_CRUISE**<br>~~=~~|Baseline forward speed during<br>CRUISE.<br>~~=~~|0–100.<br>~~=~~|
|**SPEED_TURN_INIT**<br>~~=~~|Speed while waiting for open<br>side to turn.<br>~~=~~|0–100.<br>~~=~~|
|**SPEED_TURN**<br>~~=~~|Speed duringTURNING.<br>~~=~~|0–100.<br>~~=~~|

Technical Design & Validation Report - 12 

|**SPEED_POST_TURN**<br>~~VAG~~|Speed after a turn during<br>POST_TURN.|0–100.|
|---|---|---|
|**— Driving & Safety —**<br>~~Ce~~|~~Ce~~|~~Ce~~|
|**SOFT_MARGIN**|Distance from wall when<br>gentle steering corrections<br>begin(safe_straight_control).|cm; typical 10–60.|
|**MAX_CORRECTION**<br>~~a~~|Max steering correction<br>magnitude from<br>safe_straight_control.|degrees; typical 3–15°.|
|**CORR_EPS**<br>~~a~~|cm: treat the side as 'steady' if<br>within ±1.5 cm of trigger<br>value.|Float; typical 1.5.|
|**CORRECTION_MULTIPLIER**<br>~~ee~~|Proportional gain (servo<br>degrees per cm of error 0<br>default: 2).<br>~~ee~~|Float; higher = snappier, lower<br>= smoother & slower.<br>~~ee~~|
|**STOP_THRESHOLD**<br>~~Se~~|Immediate stop if front<br>distance <<br>STOP_THRESHOLD.<br>~~Se~~|cm; typical 10–50.|
|**OBSTACLE_WAIT_TIME**<br>~~ee~~<br>~~Se~~|Time to wait while stopped<br>before retrying after an<br>obstacle stop.<br>~~ee~~<br>~~Se~~|seconds; typical 2–8s.<br>~~ee~~|
|**— Turn Management —**<br>~~Se~~<br>|~~Se~~<br>~~\\ae~~|~~ae~~|
|**FRONT_TURN_TRIGGER**<br>~~Se~~<br>~~a~~|Entering TURN_INIT when<br>front < threshold and lockout<br>allows.<br>~~Se~~<br>~~a\\ae~~|cm; typical 70–130.<br>~~ae~~|
|**TURN_DECISION_THRESHOL**<br>**D**<br>|Side considered open if<br>None/999 or > threshold.<br>~~\\ae~~|cm; typical 60–150.<br>~~ae~~|
|**TURN_ANGLE_LEFT**<br>~~es~~|Servo target to initiate left turn<br>in TURN_INIT.<br>~~es~~|degrees; ~55–90° (servo<br>scale).|
|**TURN_ANGLE_RIGHT**|Servo target to initiate right<br>turn in TURN_INIT.|degrees; ~90–125° (servo<br>scale).|
|**FRONT_SAFE_DISTANCE**<br>~~Bhd ~~|Front distance considered<br>safe to end a turn (kept for<br>reuse;not active).<br> ~~'AOO ~~|cm; 120–200+.<br> ~~GO~~|
|**SIDE_SAFE_DISTANCE**|Side distance considered safe<br>to end a turn (kept for reuse;<br>not active).|cm; 20–60.|
|**TARGET_DISTANCE**<br>~~ES~~|Desired distance from walls<br>(forpotential centering).<br>~~ES~~|cm; typical ~30.<br>~~ES~~|
|**TURN_TIMEOUT**|Maximum duration allowed for<br>TURNING before force stop.|seconds; 2–6s.|
|**TURN_LOCKOUT**<br>~~ES~~|Minimum interval between<br>consecutive turns.<br>~~ES~~|seconds; 0.5–3s.<br>~~ES~~|
|**POST_TURN_DURATION**|Straight driving duration after<br>a turn.|seconds; 0.2–1.5s.|
|**LOCK_TURN_DIRECTION**<br>~~a~~|Lock first valid turn direction<br>and keepusingit.<br>~~a~~|0 = off, 1 = on.<br>~~a~~|
|**TARGET_TURN_ANGLE**|Desired yaw change; reaching<br>within tolerance ends the turn<br>(Condition C).|degrees; 80–95°.|
|**TURN_ANGLE_TOLERANCE**<br>~~a~~|Allowed deviation from target<br>to stopthe turn.<br>~~a~~|degrees; 3–10°.<br>~~a~~|

Technical Design & Validation Report - 13 

|**MIN_TURN_ANGLE**<br>~~VAG~~|Minimum yaw change before<br>permitting stop (not currently<br>enforced).<br>|degrees; 60–80°.<br>|
|---|---|---|
|**MAX_TURN_ANGLE**<br>~~ee~~|Maximum yaw change;<br>exceeding forces stop<br>(Condition D).<br>~~ee~~|degrees; 100–130°.<br>~~ee~~|
|**— Laps —**|||
|**MAX_LAPS**<br>~~a~~|Max laps before final stop<br>(every 4 turns = 1 lap). 0 =<br>unlimited.<br>~~a~~|Integer ≥ 0; 0 = ∞.<br>~~a~~|
|**POST_LAP_DURATION**<br>~~a~~|After last lap, drive forward<br>brieflybefore stopping.<br>~~a~~|seconds; 0.5–2s.<br>~~a~~|
|**— Sensor Filtering & Ranges**<br>**—**<br>~~a~~|~~a~~|~~a~~|
|**N_READINGS**|Median window size for<br>sensor samples.|Integer ≥ 1; 1–7 typical.|
|**US_QUEUE_LEN**<br>~~gi~~|gpiozero.DistanceSensor<br>queue length for ultrasonic.<br>~~gi~~|Integer ≥ 1; default 5.<br>~~gi~~|
|**FILTER_ALPHA**|EMA smoothing for ultrasonic<br>after median.|0–1; 0.1 smooth, 1.0 none.|
|**FILTER_JUMP**<br>~~—.~~|Max allowed jump between<br>ultrasonic readings; bigger<br>jumps treated as spikes.<br>~~—.~~|cm; 10–200+, 999 disables.|
|**FILTER_ALPHA_TOF**|EMA smoothing for ToF after<br>median.|0–1; same as above.|
|**FILTER_JUMP_TOF**<br>~~|~~|Max allowed jump between<br>ToF readings before spike<br>rejection.<br>~~| ae~~|cm; 10–200+, 999 disables.<br>~~ae~~|
|**US_MAX_DISTANCE_FRONT**|Ultrasonic max distance<br>(meters) for front sensor<br>(library parameter).|meters; ~2–4m.|
|**US_MAX_DISTANCE_SIDE**<br>~~se~~|Ultrasonic max distance<br>(meters)for side sensors.<br> Vettel?|meters; ~1–3m.<br>Vettel? ~~seh~~|
|**— Loop & Plotting —**<br>||~~2~~|
|**LOOP_DELAY**<br>~~eee)~~|Main FSM loop delay; smaller<br>= more responsive but more<br>CPU.<br>~~eee)~~|seconds; 0.001–0.02.<br>~~eee)2~~|
|**SENSOR_DELAY**<br>|Sensor thread pacing; also<br>used with sensor_tick.<br>|seconds; 0.003–0.02.<br>~~2~~|
|**— Config & Scaling Bases —**<br>~~fe~~|~~fe~~|~~fe~~|
|**CONFIG_FILE**|External JSON used to<br>override defaults at startup.<br>Only keys present in globals()<br>are applied.|Path string; default<br>BASE_DIR/1st_mission_variabl<br>es.json.|

Technical Design & Validation Report - 14 

VivaLaVida WRO 2025 Future Engineers 1[st] Mission (Open Challenge) 

## **8.2 JSON Override Example** 

`1st_mission_variables.json { "USE_GUI": 0, "DEBUG": 0, "USE_TOF_SIDES": 0, "USE_TOF_FRONT": 0, "USE_TOF_CORNERS": 0, "NARROW_SUM_THRESHOLD": 60, "NARROW_HYSTERESIS": 10, "NARROW_FACTOR_SPEED": 0.6, "NARROW_FACTOR_DIST": 0.5, "SPEED_IDLE": 0, "SPEED_STOPPED": 0, "SPEED_CRUISE": 24, "SPEED_TURN_INIT": 16, "SPEED_TURN": 24, "SPEED_POST_TURN": 24, "SOFT_MARGIN": 26, "MAX_CORRECTION": 7, "CORR_EPS": 1.5, "CORRECTION_MULTIPLIER": 1.4, "STOP_THRESHOLD": 20, "OBSTACLE_WAIT_TIME": 5.0, "FRONT_TURN_TRIGGER": 90, "TURN_DECISION_THRESHOLD": 80, "TURN_ANGLE_LEFT": 61, "TURN_ANGLE_RIGHT": 119, "TURN_TIMEOUT": 2.5, "TURN_LOCKOUT": 1.5, "POST_TURN_DURATION": 0.5, "LOCK_TURN_DIRECTION": 1, "TARGET_TURN_ANGLE": 85, "TURN_ANGLE_TOLERANCE": 6, "MIN_TURN_ANGLE": 75, "MAX_TURN_ANGLE": 105, "MAX_LAPS": 3, "POST_LAP_DURATION": 0.85, "N_READINGS": 5, "US_QUEUE_LEN": 1, "FILTER_ALPHA": 1.0, "FILTER_JUMP": 9999, "FILTER_ALPHA_TOF": 1.0, "FILTER_JUMP_TOF": 9999, "US_MAX_DISTANCE_FRONT": 2.0, "US_MAX_DISTANCE_SIDE": 1.2, "LOOP_DELAY": 0.005, "SENSOR_DELAY": 0.01, "MAX_POINTS": 500 }` 

Technical Design & Validation Report - 15 

VivaLaVida WRO 2025 Future Engineers 1[st] Mission (Open Challenge) 

## **9 Appendix B - Source Code Analysis** 

## **9.1 Imports & global configuration** 

## • **External Libraries** : 

- **gpiozero** : DistanceSensor for ultrasonic sensors (distance in meters) 

- **adafruit_pca9685** : PWM control for servos and motors (50 Hz frequency) 

- **adafruit_mpu6050** : Gyroscope (Z-axis in rad/s) 

- **adafruit_vl53l0x** : Time-of-Flight (ToF) sensors (distance in mm) 

- **board/digitalio** : I²C support and XSHUT pin control for individual sensor power cycling 

- **tkinter + matplotlib** : GUI and plots for real-time data visualization 

- **numpy** : Median and mean calculations for sensor data smoothing 

- **threading** : For running parallel tasks 

- **collections.deque** : To store and manage sensor readings efficiently 

- **csv** : For exporting data to CSV format 

- **json** : For reading/writing configuration files 

- **time** : For time-related operations and delays 

## • **Configuration Constants** : 

   - Speed setpoints per FSM state: SPEED_* 

   - Turn thresholds: FRONT_TURN_TRIGGER, TURN_DECISION_THRESHOLD 

   - Safety guards: STOP_THRESHOLD, TURN_TIMEOUT, TURN_LOCKOUT, MAX_TURN_ANGLE 

   - Yaw targets: TARGET_TURN_ANGLE, TURN_ANGLE_TOLERANCE 

   - Narrow-mode thresholds: NARROW_SUM_THRESHOLD, NARROW_HYSTERESIS 

   - Filtering: FILTER_ALPHA(_TOF), FILTER_JUMP(_TOF), N_READINGS 

   - Timing: LOOP_DELAY, SENSOR_DELAY 

   - Servo geometry and pulses: SERVO_*, 1000–2000 µs 

- **Overrides** : 

   - load_variables_from_json() runs immediately after defaults so all subsequent logic uses injected values. Only keys already present in globals() are applied. 

## **9.2 Hardware Setup (GPIO/I²C, Pin Map)** 

- **GPIO Mode** : BCM 

- **LEDs** : GPIO19 (green), GPIO13 (red) 

- **Start Button** : GPIO20 (pull-up, active-LOW) 

- **I²C Devices** : 

   - PCA9685 (pca.frequency = 50) 

   - MPU6050 

   - Optional VL53L0X sensors 

- **Ultrasonic Pins** : 

   - Front: TRIG22, ECHO23 

   - Left: 27, 17 

Technical Design & Validation Report - 16 

VivaLaVida WRO 2025 Future Engineers 1[st] Mission (Open Challenge) 

   - Right: 5, 6 

   - via gpiozero.DistanceSensor (distance in meters, max_distance set per front/side) 

- **PWM Channels** : 

   - Servo on PCA channel 0 

   - Motor FWD/REV on PCA channels 1/2 

- **IMU Bias** : 

   - 500 samples averaged at boot to compute Z-gyro bias 

## **9.3 Sensor Initialization (ToF w/ XSHUT, Ultrasonic Fallback)** 

- **ToF Addressing** : 

   - Per-sensor XSHUT pins (D16/D25/D26/D24) power-cycle and set unique I²C addresses (0x30–0x33) 

   - Start continuous with a 20 ms budget for each sensor 

- **Fallback** : 

   - Any ToF initialization exception disables ToF flags and uses ultrasonics for the affected directions 

- **Mixed Mode** : 

   - Front/side ToF enablement is independent. For example, you can run ultrasonic on sides and ToF on the front (or vice-versa). 

## **9.4 Data Model & Threading Primitives** 

- **Shared Sensor Snapshot** : 

   - sensor_data = {"front":…, "left":…, "right":…} guarded by a Lock 

- **Events** : 

   - readings_event (sensors armed) 

   - loop_event (FSM armed) 

   - sensor_tick (timed wait with immediate wake for quick responsiveness) 

- **Telemetry** : 

   - Deques (time_data, front/left/right_data, angle_data, state_data) with MAX_POINTS cap for plots/CSV export 

## **9.5 RobotController (Low-Level Actuation & Signal Processing)** 

- **Servo Command** : 

   - set_servo(angle) clamps to [SERVO_MIN_ANGLE, SERVO_MAX_ANGLE] 

   - Pulse conversion: 

      - pulse_us = SERVO_PULSE_MIN + (SERVO_PULSE_MAX - SERVO_PULSE_MIN) 

         - → 

         - * (angle - MIN) / (MAX - MIN) PCA duty (0..65535) 

- **Motor Command** : 

   - rotate_motor(speed) maps 0–100% to PCA duty; selects FWD vs REV channel by sign 

   - stop_motor() zeros both PWM channels 

- **Distance Filtering** : 

   - filtered_distance(sensor, history, attr, sensor_type) applies median over last N_READINGS, rejects spikes greater than |FILTER_JUMP| vs previous readings, and applies an Exponential Moving Average (EMA): 

      - y = α·x + (1−α)·y_prev 

   - Returns smoothed distance in cm or 999 sentinel for invalid data 

Technical Design & Validation Report - 17 

VivaLaVida WRO 2025 Future Engineers 1[st] Mission (Open Challenge) 

## • **Lane-Keeping** : 

   - safe_straight_control(l,r) computes bounded correction using eff_soft_margin() and eff_max_correction() (scaled by narrow-mode factors), returns a target servo angle. 

- **Turn Helper** : 

   - turn_decision(l,r) → "LEFT", "RIGHT", or None using XOR (open_left, open_right - only one Input is True) where “open” is (None or 999 or > TURN_DECISION_THRESHOLD). 

## **9.6 Real-Time Threads** 

- **sensor_reader (period ≈ SENSOR_DELAY)** : 

   - Acquires left/right/front sensor data (either ToF or US), applies filters, writes to sensor_data under Lock 

   - Sleeps with sensor_tick.wait(SENSOR_DELAY) (can be preemptively woken) 

- **robot_loop (soft-real-time main loop)** : 

   - If readings_event is not set → hold IDLE state. 

   - On each tick: copy snapshot, update yaw, narrow-mode, telemetry, then run FSM if loop_event is set. 

## **9.7 Yaw Integration & Units** 

   - **IMU Input** : 

      - gyro_z in rad/s, bias-corrected, low-passed (ALPHA), integrated to degrees: 

         - yaw += (gyro_z_filtered * RAD2DEG) * dt, where RAD2DEG = 180/π, dt from monotonic_ns() 

- **9.8 Finite State Machine (FSM)** 

   - **States** : 

   - IDLE → CRUISE → TURN_INIT → TURNING → POST_TURN → STOPPED 

   - **Key Transitions & Guards** : 

   - → 

   - **Emergency Stop (Anywhere)** : front < eff_stop_threshold() STOPPED, schedule auto-retry for OBSTACLE_WAIT_TIME 

   - **→** 

   - **Turn Eligibility (CRUISE TURN_INIT)** : front < eff_front_turn_trigger() and (now − last_turn_time) ≥ TURN_LOCKOUT 

   - **Direction Selection (TURN_INIT)** : Require XOR (open_left, open_right - only one Input is True); if LOCK_TURN_DIRECTION=1, fix first chosen direction for the run; else, keep waiting at SPEED_TURN_INIT 

   - **Turn Commit (→ TURNING)** : Set servo to TURN_ANGLE_LEFT/RIGHT, record turn_start_yaw/time, run at SPEED_TURN 

   - **Turn Termination (TURNING → POST_TURN)** : 

   - Primary: |Δyaw − TARGET_TURN_ANGLE| ≤ TURN_ANGLE_TOLERANCE 

   - Failsafes: (now − turn_start_time) > TURN_TIMEOUT or |Δyaw| ≥ MAX_TURN_ANGLE 

   - On stop: center servo, last_turn_time = now, optionally snap yaw to exact target for continuity, → 

   - increment turn_count; every 4 turns lap_count++ (stop after MAX_LAPS with POST_LAP_DURATION forward). 

   - **→** 

   - **Post-Turn (POST_TURN CRUISE)** : Hold straight for POST_TURN_DURATION. 

## **9.9 Environment Adaptation (Narrow-Mode)** 

- **Detector** : 

Technical Design & Validation Report - 18 

VivaLaVida WRO 2025 Future Engineers 1[st] Mission (Open Challenge) 

   - Compute sum_lr = left + right for valid readings; enter if < NARROW_SUM_THRESHOLD, exit if > threshold + NARROW_HYSTERESIS 

- **Scaling** : 

   - Set SPEED_ENV_FACTOR and DIST_ENV_FACTOR; all eff_* helpers (e.g., eff_soft_margin(), eff_front_turn_trigger()) and state_speed_value() consume these to adapt behavior without changing base constants. 

## **9.10 GUI Subsystem (For Debugging)** 

- **Tkinter UI** : 

   - Buttons (Start Readings, Start Loop, Stop Loop), status label, circular state indicator, turn/lap counters. 

- **Plots** : 

   - 3 Matplotlib subplots (front, side [left vs −right], yaw); dynamic x-window, last-value annotations, and after() updates (100–200 ms) 

- **Sliders** : 

   - Grouped controls for speeds, margins, triggers, timeouts; write through to globals() 

   - Save/load JSON presets 

- **Export** : 

   - export_data_csv() writes time series + current state + slider snapshot for reproducibility 

- **Shutdown** : 

   - on_closing() calls stop_loop(), stops ToF continuous mode, cleanup 

## **9.11 Start/Stop & Lifecycle** 

- **Handlers** : 

   - start_readings() spawns sensor_reader (daemon) and robot_loop (daemon) once 

   - start_loop() sets loop_event 

   - stop_loop() clears loop, records stop_reason, resets counters, unlocks direction, centers servo, stops motor 

- **Headless Path (__main__)** : 

   - LEDs signal readiness; wait for physical Start (active-LOW); then set events and run robot_loop() in the foreground. 

   - KeyboardInterrupt and GUI close lead to clean shutdown. 

## **9.12 Synchronization & Timing** 

- **Progress Gating** : 

   - readings_event must be set before any motion 

   - loop_event controls whether FSM drives motors (plots still update while off) 

- **Wait Strategy** : 

   - sensor_tick.wait(…) used instead of time.sleep() so stop_loop() can set() to break out immediately 

- **Typical Periods** : 

   - SENSOR_DELAY ≈ 5 ms (up to ~200 Hz raw read cadence) 

   - Main loop LOOP_DELAY ≈ 1 ms cap (effective rate bounded by processing and GUI) 

Technical Design & Validation Report - 19 

VivaLaVida WRO 2025 Future Engineers 1[st] Mission (Open Challenge) 

## **9.13 Safety/Fallbacks** 

- **Bounds** : 

   - All servo angles clamped 

   - Motor duty bounded to 0–100% 

- **Guards** : 

   - Emergency stop, turn timeout, max turn angle, turn lockout 

   - Narrow-mode scaling to reduce risk in tight corridors 

- **Sensor Resilience** : 

   - Jump-rejection, EMA smoothing, 999 sentinel for invalid 

   - Automatic ToF→US fallback on init failure 

## **9.14 Thread Summary** 

- **sensor_reader** — acquisition + filtering (median → spike reject → EMA) → publish under Lock 

- → 

- **robot_loop** — yaw integration (rad/s deg), narrow-mode, FSM, PWM outputs via PCA9685, telemetry append 

- **GUI (optional)** — plotting, parameter sliders with live writes, CSV export, start/stop controls 

Events: readings_event, loop_event, sensor_tick avoid busy-waiting and keep latency low. 

Technical Design & Validation Report - 20 

VivaLaVida 

WRO 2025 Future Engineers 1[st] Mission (Open Challenge) 

## **10 Appendix C - Source code** 

`0010: #--------------------------------------------------------------------------------------------0011: # 1st Mission WRO 2025 FE - VivaLaVida 0012: # Final Version 0013: #--------------------------------------------------------------------------------------------0014: 0015: # =============================== 0016: # IMPORTS 0017: # =============================== 0018: 0019: 0020: import os, sys 0021: 0022: VENV_PY = "/home/stem/env/bin/python"  # exact path to Python in your venv 0023: 0024: if sys.executable != VENV_PY and os.path.exists(VENV_PY): 0025:     print(f"[INFO] Relaunching under virtual environment: {VENV_PY}", flush=True) 0026:     os.execv(VENV_PY, [VENV_PY] + sys.argv) 0027: 0028: # --- your normal robot code below --0029: print(f"[INFO] Now running inside: {sys.executable}") 0030: 0031: 0032: import threading 0033: import time 0034: from collections import deque 0035: import busio 0036: from adafruit_pca9685 import PCA9685 0037: import adafruit_mpu6050 0038: import csv 0039: from datetime import datetime 0040: import json 0041: 0042: import board 0043: import digitalio 0044: import adafruit_vl53l0x 0045: from enum import Enum, auto 0046: import numpy as np 0047: from gpiozero import Device 0048: from gpiozero.pins.lgpio import LGPIOFactory   # Uses /dev/gpiochip* 0049: Device.pin_factory = LGPIOFactory() 0050: from gpiozero import Button, LED 0051: from gpiozero import DistanceSensor 0052: from threading import Event 0053: 0054: BASE_DIR = os.path.dirname(os.path.abspath(__file__)) # Get directory of the running script 0055: CONFIG_FILE = os.path.join(BASE_DIR, "1st_mission_variables.json") 0056: 0057: # =============================== 0058: # CONFIGURATION VARIABLES 0059: # =============================== 0060: 0061: # ---------- Initialization ---------0062: USE_GUI = 0                   # 1 = Debugging mode (run with GUI), 0 = COMPETITION MODE (run headless, no GUI) 0063: DEBUG = 0                     # 1 = enable prints, 0 = disable all prints 0064: USE_TOF_SIDES = 0             # Side sensors:  0 = Ultrasonic, 1 = ToF 0065: USE_TOF_FRONT = 0             # Front sensor:  0 = Ultrasonic, 1 = ToF 0066: USE_TOF_CORNERS = 0           # Front side sensor: 0 = disable, 1 = enable 0067: 0068: NARROW_SUM_THRESHOLD = 60     # cm; left+right distance threshold to decide if in between narrow walls 0069: NARROW_HYSTERESIS = 10        # cm; prevents rapid toggling 0070: NARROW_FACTOR_SPEED = 0.6     # multiply state speeds when in narrow corridors 0071: NARROW_FACTOR_DIST  = 0.5     # multiply distance-based thresholds/corrections when in narrow corridors 0072: 0073: # ---------- Speeds ---------0074: SPEED_IDLE = 0 0075: SPEED_STOPPED = 0 0076: SPEED_CRUISE = 24             # Motor speed for normal straight driving (0-100%) 0077: SPEED_TURN_INIT = 16          # Motor speed while waiting for open side to turn 0078: SPEED_TURN = 24               # Motor speed while turning 0079: SPEED_POST_TURN = 24          # Motor speed following a turn` 

Technical Design & Validation Report - 21 

WRO 2025 Future Engineers 1[st] Mission (Open Challenge) 

## VivaLaVida 

`0080:` 

`0081: # ---------- Driving ---------0082: SOFT_MARGIN = 26              # Distance from wall where small steering corrections start (cm) 0083: MAX_CORRECTION = 7            # Maximum servo correction applied for wall-following (degrees) 0084: CORR_EPS = 1.5                # cm: treat the side as "steady" if within ±1.5 cm of trigger value 0085: CORRECTION_MULTIPLIER = 1.4   # Proportional gain (servo degrees per cm of error 0 default: 2). Higher = snappier; lower = smoother&slower. 0086: 0087: STOP_THRESHOLD = 20           # Front distance (cm) at which robot stops immediately 0088: OBSTACLE_WAIT_TIME = 5.0      # seconds to wait before retrying after a front-stop 0089: 0090: # ---------- Turn management ---------0091: FRONT_TURN_TRIGGER = 90       # Front distance (cm) at which a turn is triggered 0092: TURN_DECISION_THRESHOLD = 80  # Minimum side distance (cm) to allow turn in that direction 0093: TURN_ANGLE_LEFT = 61          # Servo angle for left turn 0094: TURN_ANGLE_RIGHT = 119        # Servo angle for right turn 0095: TURN_TIMEOUT = 2.5            # Maximum time allowed for a turn (seconds) 0096: TURN_LOCKOUT = 1.5            # Minimum interval between consecutive turns (seconds) 0097: POST_TURN_DURATION = 0.5      # Time to drive straight after a turn (seconds) 0098: LOCK_TURN_DIRECTION = 1       # 1 = enable turn lock direction after 1st turn, 0 = disable 0099: TARGET_TURN_ANGLE = 85        # Degrees to turn per corner 0100: TURN_ANGLE_TOLERANCE = 6      # Acceptable overshoot (degrees) 0101: 0102: # ---------- Turn angle constraints ---------0103: MIN_TURN_ANGLE = 75           # Minimum yaw change (degrees) before turn can stop 0104: MAX_TURN_ANGLE = 105          # Maximum yaw change (degrees) to force stop turn 0105: 0106: # ---------- Laps ---------0107: MAX_LAPS = 3                  # Maximum number of laps before stopping (0 = unlimited) 0108: POST_LAP_DURATION = 0.85         # Time to drive forward after final lap before stopping (seconds) 0109: 0110: # ---------- Sensor data filtering ---------0111: N_READINGS = 5                # Number of readings stored for median filtering 0112: US_QUEUE_LEN = 1              # Queue_len for Ultrasonic gpiozero.DistanceSensor 0113: FILTER_ALPHA = 1.0            # Ultrasonic 0.1 = smoother, 0.5 = faster reaction, 1 to ignore filter 0114: FILTER_JUMP = 9999            # Ultrasonic maximum jump (cm) allowed between readings 0115: FILTER_ALPHA_TOF = 1.0        # ToF 0.1 = smoother, 0.5 = faster reaction, 1 to ignore filter 0116: FILTER_JUMP_TOF = 9999        # ToF maximum jump (cm) allowed between readings 0117: 0118: US_MAX_DISTANCE_FRONT = 2.0  # Ultrasonic front max read distance 0119: US_MAX_DISTANCE_SIDE = 1.2   # Ultrasonic side max read distance 0120: 0121: # ---------- Loop timing ---------0122: LOOP_DELAY = 0.005            # Delay between main loop iterations (seconds) 0.02 0123: SENSOR_DELAY = 0.01          # Delay between sensor reads 0124: 0125: #----------------------------------------------------------------------------------------0126: 0127: # ---------- Plotting ---------0128: MAX_POINTS = 500               # Maximum number of points to store for plotting 0129: 0130: RAD2DEG = 180.0 / 3.141592653589793 0131: 0132: # --- I2C concurrency guard --0133: I2C_LOCK = threading.Lock() 0134: 0135: def dprint(*args, **kwargs): #Conditional print — only prints when DEBUG == 1. 0136:     if DEBUG:` 

`0137:         print(*args, **kwargs) 0138: 0139: # --- Headless-safe placeholders for GUI symbols --0140: slider_vars = {} 0141: btn_readings = btn_start = btn_stop = None 0142: lbl_turns = lbl_laps = None` 

`0143: root = canvas = None 0144: 0145: # ===============================` 

`0146: # LOAD VARIABLES FROM JSON (if exists) 0147: # =============================== 0148:` 

`0149: def load_variables_from_json(path=CONFIG_FILE): # Override defaults with values from JSON if the file exists.` 

`0150:     if not os.path.exists(path):` 

`0151:         print(" No external config found — using built-in defaults.")` 

Technical Design & Validation Report - 22 

VivaLaVida 

WRO 2025 Future Engineers 1[st] Mission (Open Challenge) 

`0152:         return 0153:     try: 0154:          with open(path, "r") as f: 0155:               data = json.load(f) 0156:          count = 0 0157:          for k, v in data.items(): 0158:              if k in globals(): 0159:                  globals()[k] = v 0160:                  count += 1` 

`0161:          print(f" Loaded {count} variables from {os.path.basename(path)}") 0162:     except Exception as e: 0163:          print(f"[ERROR] Config load failed: {e} — using built-in defaults.") 0164: 0165: load_variables_from_json() # Call it right after defining defaults so everything below sees the overrides 0166: 0167: if os.environ.get("DISPLAY", "") == "": # If there is no X server, force headless regardless of config 0168:     USE_GUI = 0 0169: 0170: def norm180(a: float) -> float: # Normalize angle to [-180, 180) 0171:     return (a + 180.0) % 360.0 - 180.0 0172: 0173: def snap90(a: float) -> float: # Nearest multiple of 90° (…,-180,-90,0,90,180,…) 0174:     return round(a / 90.0) * 90.0 0175: 0176: # --- Store immutable base values for scaling --0177: BASE_SPEED_IDLE        = SPEED_IDLE 0178: BASE_SPEED_STOPPED     = SPEED_STOPPED 0179: BASE_SPEED_CRUISE      = SPEED_CRUISE 0180: BASE_SPEED_TURN_INIT   = SPEED_TURN_INIT 0181: BASE_SPEED_TURN        = SPEED_TURN 0182: BASE_SPEED_POST_TURN   = SPEED_POST_TURN 0183: 0184: BASE_MAX_CORRECTION     = MAX_CORRECTION 0185: BASE_FRONT_TURN_TRIGGER = FRONT_TURN_TRIGGER 0186: BASE_STOP_THRESHOLD     = STOP_THRESHOLD 0187: 0188: # --- Global factors (automatically updated) --0189: SPEED_ENV_FACTOR = 1.0 0190: DIST_ENV_FACTOR  = 1.0  # for distance-related thresholds 0191: 0192: # --- Helper functions to get "effective" (scaled) values --0193: def eff_soft_margin(): #Return scaled soft margin distance (cm) for gentle steering corrections 0194:     return int(SOFT_MARGIN * DIST_ENV_FACTOR) 0195: 0196: def eff_max_correction(): #Return scaled maximum steering correction (degrees) 0197:     return max(1, int(MAX_CORRECTION * DIST_ENV_FACTOR)) 0198: 0199: def eff_front_turn_trigger(): #Return scaled front distance threshold (cm) for initiating a turn 0200:     return int(FRONT_TURN_TRIGGER * DIST_ENV_FACTOR) 0201: 0202: def eff_stop_threshold(): #Return scaled front distance threshold (cm) for immediate stop 0203:     return int(STOP_THRESHOLD * DIST_ENV_FACTOR) 0204: 0205: # --- Scaled state speeds --0206: def state_speed_value(state_name: str) -> int: 0207:     base = { 0208:         "IDLE":      SPEED_IDLE, 0209:         "STOPPED":   SPEED_STOPPED, 0210:         "CRUISE":    SPEED_CRUISE, 0211:         "TURN_INIT": SPEED_TURN_INIT, 0212:         "TURNING":   SPEED_TURN, 0213:         "POST_TURN": SPEED_POST_TURN, 0214:     }.get(state_name, SPEED_CRUISE) 0215:     return int(base * SPEED_ENV_FACTOR) 0216: 0217: def headless_toggle_pause(): #Toggle pause/resume of the driving loop in headless mode 0218:     global paused_by_button, status_text 0219:     if loop_event.is_set(): #Pause 0220:         loop_event.clear() 0221:         paused_by_button = True 0222:         robot.stop_motor() 0223:         robot.set_servo(SERVO_CENTER) 0224:         RED_LED.off()     # paused` 

Technical Design & Validation Report - 23 

VivaLaVida 

WRO 2025 Future Engineers 1[st] Mission (Open Challenge) 

|VAW|WRO 2025 Future Engineers 1[st]Mission (Open Challenge)<br>VAW|
|---|---|
|0225: GREEN_LED.on()|0225: GREEN_LED.on()|
|0226: status_text = "Paused (button)"|0226: status_text = "Paused (button)"|
|0227: else:  # RESUME|0227: else:  # RESUME|
|0228: paused_by_button = False|0228: paused_by_button = False|
|0229: loop_event.set()|0229: loop_event.set()|
|0230: GREEN_LED.off() # running|0230: GREEN_LED.off() # running|
|0231: RED_LED.on()|0231: RED_LED.on()|
|0232: status_text = "|0232: status_text = " Resumed"|
|0233:|0233:|
|0234: # ===============================|0234: # ===============================|
|0235: # HARDWARE SETUP|0235: # HARDWARE SETUP|
|0236: # ===============================|0236: # ===============================|
|0237:|0237:|
|0238: i2c = busio.I2C(board.SCL, board.SDA)|0238: i2c = busio.I2C(board.SCL, board.SDA)|
|0239:|0239:|
|0240: # ---------- Button & LEDs (gpiozero-based) ----------|0240: # ---------- Button & LEDs (gpiozero-based) ----------|
|0241: START_BTN = Button(20, pull_up=True, bounce_time=0.03)|0241: START_BTN = Button(20, pull_up=True, bounce_time=0.03)|
|0242: GREEN_LED = LED(19)|0242: GREEN_LED = LED(19)|
|0243: RED_LED = LED(13)|0243: RED_LED = LED(13)|
|0244: #|0244: # Turn RED on as soon as the program starts|
|0245: RED_LED.on()|0245: RED_LED.on()|
|0246:|0246:|
|0247: # ---------- Ultrasonic sensor pins ----------|0247: # ---------- Ultrasonic sensor pins ----------|
|0248: TRIG_FRONT, ECHO_FRONT = 22, 23  # GPIO pins for front sensor|0248: TRIG_FRONT, ECHO_FRONT = 22, 23  # GPIO pins for front sensor|
|0249: TRIG_LEFT, ECHO_LEFT = 27, 17 # GPIO pins for left sensor|0249: TRIG_LEFT, ECHO_LEFT = 27, 17 # GPIO pins for left sensor|
|0250: TRIG_RIGHT, ECHO_RIGHT = 5, 6 # GPIO pins for right sensor|0250: TRIG_RIGHT, ECHO_RIGHT = 5, 6 # GPIO pins for right sensor|
|0251:|0251:|
|0252: # ---------- Motor ----------|0252: # ---------- Motor ----------|
|0253: MOTOR_FWD = 1 # PCA9685 channel for forward motor control|0253: MOTOR_FWD = 1 # PCA9685 channel for forward motor control|
|0254: MOTOR_REV = 2 # PCA9685 channel for reverse motor control|0254: MOTOR_REV = 2 # PCA9685 channel for reverse motor control|
|0255:|0255:|
|0256: # ---------- Servo ----------|0256: # ---------- Servo ----------|
|0257: SERVO_CHANNEL = 0 # PCA9685 channel controlling steering servo|0257: SERVO_CHANNEL = 0 # PCA9685 channel controlling steering servo|
|0258: SERVO_CENTER = 90 # Neutral servo angle (degrees)|0258: SERVO_CENTER = 90 # Neutral servo angle (degrees)|
|0259: SERVO_MIN_ANGLE = 50 # Minimum physical servo angle (degrees)|0259: SERVO_MIN_ANGLE = 50 # Minimum physical servo angle (degrees)|
|0260: SERVO_MAX_ANGLE = 130 # Maximum physical servo angle (degrees)|0260: SERVO_MAX_ANGLE = 130 # Maximum physical servo angle (degrees)|
|0261: SERVO_PULSE_MIN = 1000 # Minimum PWM pulse width (microseconds)|0261: SERVO_PULSE_MIN = 1000 # Minimum PWM pulse width (microseconds)|
|0262: SERVO_PULSE_MAX = 2000 # Maximum PWM pulse width (microseconds)|0262: SERVO_PULSE_MAX = 2000 # Maximum PWM pulse width (microseconds)|
|0263: SERVO_PERIOD = 20000 # Servo PWM period (microseconds)|0263: SERVO_PERIOD = 20000 # Servo PWM period (microseconds)|
|0264:|0264:|
|0265: # ===============================|0265: # ===============================|
|0266: # SENSOR INITIALIZATION (ToF + Ultrasonic)|0266: # SENSOR INITIALIZATION (ToF + Ultrasonic)|
|0267: # ===============================|0267: # ===============================|
|0268:|0268:|
|0269: vl53_left = vl53_right = vl53_front = vl53_back = None|0269: vl53_left = vl53_right = vl53_front = vl53_back = None|
|0270: vl53_front_left = vl53_front_right = None|0270: vl53_front_left = vl53_front_right = None|
|0271: us_left = us_right = us_front = None|0271: us_left = us_right = us_front = None|
|0272:|0272:|
|0273: try:|0273: try:|
|0274: # --------- ToF sensors ----------|0274: # --------- ToF sensors ----------|
|0275: if USE_TOF_SIDES or USE_TOF_FRONT or USE_TOF_CORNERS:|0275: if USE_TOF_SIDES or USE_TOF_FRONT or USE_TOF_CORNERS:|
|0276: print("Initializing VL53L0X ToF sensors...")|0276: print("Initializing VL53L0X ToF sensors...")|
|0277: # XSHUT pins setup (for powering sensors individually)|0277: # XSHUT pins setup (for powering sensors individually)|
|0278: xshut_left  = digitalio.DigitalInOut(board.D16)|0278: xshut_left  = digitalio.DigitalInOut(board.D16)|
|0279: xshut_right = digitalio.DigitalInOut(board.D25)|0279: xshut_right = digitalio.DigitalInOut(board.D25)|
|0280: xshut_front = digitalio.DigitalInOut(board.D26)|0280: xshut_front = digitalio.DigitalInOut(board.D26)|
|0281: xshut_back  = digitalio.DigitalInOut(board.D8)|0281: xshut_back  = digitalio.DigitalInOut(board.D8)|
|0282: xshut_front_left  = digitalio.DigitalInOut(board.D7)|0282: xshut_front_left  = digitalio.DigitalInOut(board.D7)|
|0283: xshut_front_right = digitalio.DigitalInOut(board.D24)|0283: xshut_front_right = digitalio.DigitalInOut(board.D24)|
|0284: for xshut in [xshut_left, xshut_right, xshut_front, xshut_back,|0284: for xshut in [xshut_left, xshut_right, xshut_front, xshut_back,|
|0285: xshut_front_left, xshut_front_right]:|0285: xshut_front_left, xshut_front_right]:|
|0286: xshut.direction = digitalio.Direction.OUTPUT|0286: xshut.direction = digitalio.Direction.OUTPUT|
|0287: xshut.value = False  # power down|0287: xshut.value = False  # power down|
|0288: time.sleep(0.1)|0288: time.sleep(0.1)|
|0289:|0289:|
|0290: # Initialize left ToF if needed|0290: # Initialize left ToF if needed|
|0291: if USE_TOF_SIDES:|0291: if USE_TOF_SIDES:|
|0292: xshut_left.value = True|0292: xshut_left.value = True|
|0293: time.sleep(0.05)|0293: time.sleep(0.05)|
|0294: vl53_left = adafruit_vl53l0x.VL53L0X(i2c)|0294: vl53_left = adafruit_vl53l0x.VL53L0X(i2c)|
|0295: vl53_left.set_address(0x30)|0295: vl53_left.set_address(0x30)|
|0296: vl53_left.measurement_timing_budget = 20000|0296: vl53_left.measurement_timing_budget = 20000|
|0297: vl53_left.start_continuous()|0297: vl53_left.start_continuous()|
|0298: print("|0298: print(" Left ToF sensor set to address 0x30")|
|0299:|0299:|
|0300: # Initialize right ToF if needed|0300: # Initialize right ToF if needed|
|0301: if USE_TOF_SIDES:|0301: if USE_TOF_SIDES:|

Technical Design & Validation Report - 24 

WRO 2025 Future Engineers 1[st] Mission (Open Challenge)
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



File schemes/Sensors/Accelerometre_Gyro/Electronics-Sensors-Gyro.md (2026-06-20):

# Gyroscope

The selected sensor suite is engineered to provide the robot with **robust, real-time spatial awareness** under the constraints of the WRO 2025 FE environment. Each sensor category contributes different strengths: short-range precision, long-range detection, and orientation stability. Together, they form a redundant, multi-modal perception system that enables reliable autonomous navigation even in unpredictable wall placements and obstacle scenarios.

---

## 1 Acceleration and Rotation Sensors

---

## a) IMU – GY-521 (MPU6050)

The IMU provides essential orientation data that replaces wheel encoders. The robot relies on **gyro integration** to maintain heading and stability across the 3×3m field.

### Purpose in the Robot
- **Yaw estimation** for straight-line driving.
- Stabilized **turning angles** and orientation resets.
- Compensation for wheel slip or irregular surfaces.

### MPU6050 Technical Specifications
- **Sensor type:** 6-axis IMU  
  - 3-axis gyroscope  
  - 3-axis accelerometer  
- **Interface:** I²C (3.3 V logic)
- **Gyroscope range:** ±250 / ±500 / ±1000 / ±2000 °/s
- **Accelerometer range:** ±2g / ±4g / ±8g / ±16g
- **Gyro sensitivity:** 131 LSB/(°/s) at ±250 setting
- **Sampling:** up to 1 kHz
- **DMP:** available but not used in this project
- **Power:** 3.3–5 V (regulated to 3.3 V onboard)

### Why IMU is Essential
- Robot **does not use wheel encoders**, so IMU is the only odometry feedback.
- Provides smooth trajectory correction.
- Detects drift over long straight segments.

---

## 3 Optional / “Not Used” Sensors

The PCB includes footprints for possible expansion modules:

- Colour sensor  
- OLED diagnostic display  
- Extra tactile button  
- Piezo buzzer  
- DIP configuration switch  
- LIDAR interface header  

These are currently **NOT USED**, but the PCB layout supports future features such as color-based decision making, on-device debugging, or long-range scanning without redesigning the hardware.

---

## Alternative Sensors Considered

Several alternative sensing technologies were evaluated but not selected due to cost or complexity.

### 1. IMU with Magnetometer (LSM6DS3)
- Pros: absolute north-based heading
- Cons: indoor magnetic interference makes it unreliable on metal-frame competition tables

---

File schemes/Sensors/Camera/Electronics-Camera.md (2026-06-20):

# For our camera we chose: The ArduCam IMX219 

## Why we chose it

## Characteristics
The IMX219 is a powerful camera module that offers:
  - Wide-angle fisheye lens
  - High resolution of 8 MP
  - Good low-noise performance for a small camera module

---

## Compatibility
The IMX219 integrates easily with:
  - Raspberry Pi 5 
  - Python, using libraries such as OpenCV
  - OpenCV, allowing advanced image processing and computer-vision algorithms

---

## Alternatives
Raspberry Pi Camera Module V3:
- **Pros:**
  - Better compatibility with the Raspberry Pi 5
  - Newer autofocus system
- **Cons:**
   -Lower resolution compared to the IMX219
  - Narrower field of view than the fisheye IMX219

---

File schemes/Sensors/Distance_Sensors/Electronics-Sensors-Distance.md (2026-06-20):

# Distance Sensors – Why This Combination

The selected sensor suite is engineered to provide the robot with **robust, real-time spatial awareness** under the constraints of the WRO 2025 FE environment. Each sensor category contributes different strengths: short-range precision, long-range detection, and orientation stability. Together, they form a redundant, multi-modal perception system that enables reliable autonomous navigation even in unpredictable wall placements and obstacle scenarios.

---

## 1 Distance Metering Sensors

---

## a) Time-of-Flight (ToF) Sensors – VL53L0X

Time-of-Flight sensors are used for **high-precision, short-range** distance measurement. They operate using **laser-based VCSEL emitters** and measure the time taken for light to return from a surface.

### Purpose in the Robot
- Provide high-resolution (<5 mm) distance data for **close-proximity navigation**.
- Essential for **unparking logic** during the obstacle challenge.
- More reliable on **dark, matte, or angled surfaces** compared to ultrasonics.
- Excellent in detecting narrow gaps or side distances during tight maneuvers.

### Hardware & Positioning
Six (6) **VL53L0X** modules are mounted around the chassis:
        Front
Left-Front Right-Front
Left             Right
        Back

### VL53L0X Technical Specifications
- **Sensor type:** Time-of-Flight (laser ranging, VCSEL)
- **Interface:** I²C (400 kHz Fast Mode)
- **Operating voltage:** 2.6–5 V (5 V rail used)
- **Range:** 2–200 cm (optimal precision <50 cm)
- **Resolution:** ±3 mm typical
- **Field of View:** ~25°
- **Measurement speed:** up to 50 Hz
- **Key advantage:** immune to acoustic noise and surface angle variability

---

## b) Ultrasonic Sensors – HC-SR04

Ultrasonic sensors provide **long-range detection** using acoustic pulses, complementing the short-range precision of the ToF sensors.

### Purpose in the Robot
- Detect walls and open space at distances **up to 3m**.
- Used during **cruising**, **turn decisions**, and **wall-following**.
- Redundant to ToF for improved situational awareness.

### Hardware & Positioning
Three (3) **HC-SR04** units are mounted:
        Front
Left             Right

### HC-SR04 Technical Specifications
- **Sensor type:** ultrasonic (40 kHz)
- **Operating voltage:** 5 V (with resistor divider on echo → 3.3 V GPIO safe)
- **Range:** 2–400 cm
- **Resolution:** ~3 mm
- **Beam angle:** ~15°
- **Trigger pulse:** 10 µs
- **Sampling frequency:** ~20 Hz
- **Limitations:** acoustic reflections, noise spikes, angle-dependent accuracy

### Combined Benefits (ToF + Ultrasonic)
Using both categories produces a robust hybrid sensing model:

- **Short-range precision** (ToF)
- **Long-range awareness** (ultrasonic)
- **Redundancy** when one fails due to:
  - acoustic noise
  - reflective surfaces
  - angled walls causing weak returns

---

## 3 Optional / “Not Used” Sensors

The PCB includes footprints for possible expansion modules:

- Colour sensor  
- OLED diagnostic display  
- Extra tactile button  
- Piezo buzzer  
- DIP configuration switch  
- LIDAR interface header  

These are currently **NOT USED**, but the PCB layout supports future features such as color-based decision making, on-device debugging, or long-range scanning without redesigning the hardware.

---

## Final Outcome – Sensor Roles in the Final Design

After extensive testing:

### ToF – Final Evaluation
- **Pros**
  - Excellent <30 cm accuracy  
  - Very stable readings (low noise)  
  - Resistant to dark/angled surfaces  
- **Cons**
  - Limited practical range (>30–50 cm unreliable in vertical-wall environments)

### Ultrasonic – Final Evaluation
- **Pros**
  - Reliable long-range detection (>1 m)  
  - Good for early warning of walls  
- **Cons**
  - Susceptible to noise, reflections, and angle errors  

### Final Usage
- **Ultrasonic sensors**  
  - Used during **cruising**, **turning decisions**, and **general wall-following**.  
- **ToF sensors**  
  - Used for **unparking decisions** in the obstacle challenge.  
  - Used for precise short-range calibrations.

---

## Alternative Sensors Considered

Several alternative sensing technologies were evaluated but not selected due to cost or complexity.

### 1. Infrared (IR) Proximity Sensors
- Pros: cheap, wide availability  
- Cons: poor performance in ambient light, reflective-surface errors

### 2. [Lidar](https://github.com/VIVA-LA-VIDA-Hellas/VIVA-LA-VIDA/blob/main/Vehicle/Compartments/Lidar.md)
- Pros: full 360° mapping, excellent accuracy  
- Cons: too large, too heavy, not allowed or impractical for WRO FE robot dimensions

### 3. Wheel Encoders
- Pros: accurate drive-distance estimation  
- Cons: add mechanical complexity; unreliable due to robot vibrations and tight-turn requirements

### 4. Depth Cameras (Intel RealSense)
- Pros: high-resolution 3D obstacle detection  
- Cons: expensive, high power consumption, overkill for 3×3 m field

---

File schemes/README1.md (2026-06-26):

# This directory consists of the electromechanical components used for this project, as well as further information about them such as, justification of use, component characteristics and discriptive photos explaining the different parts of the PCB placket utilized 

## Mechanical Components (motor, servo, sensors)
## Discriptive PCB Photos
### Top
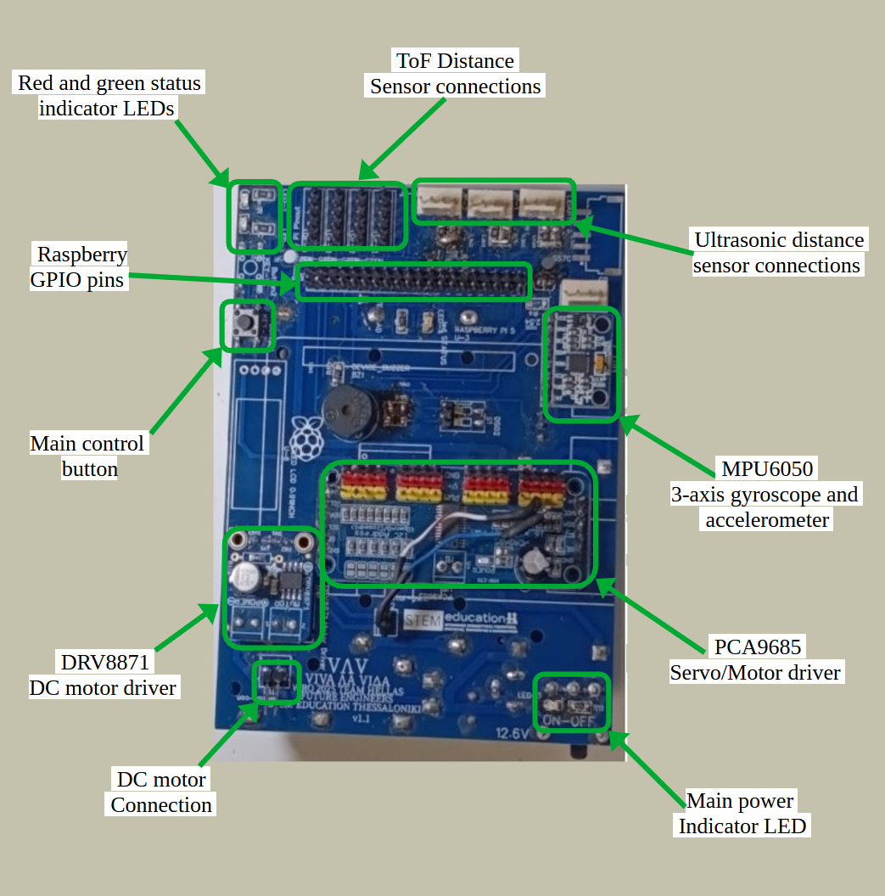
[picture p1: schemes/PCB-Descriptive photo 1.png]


### Bottom
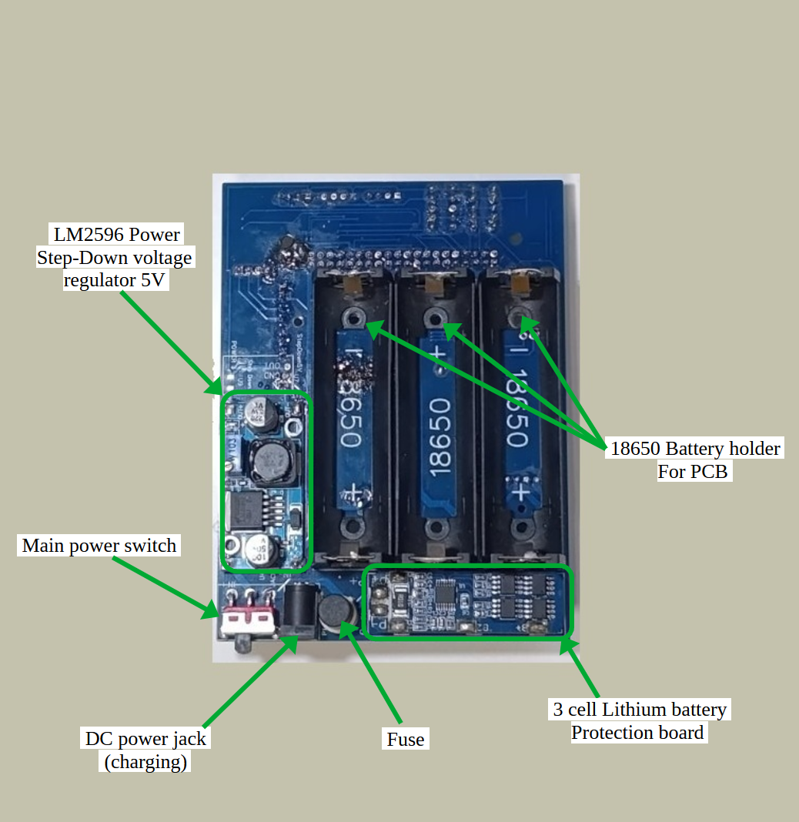
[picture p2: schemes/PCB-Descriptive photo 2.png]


## Final PCB design layout 

### Top and bottom compartments of the PCB
top side PCB
bottom pcb

### Top layer
red seperate (top) PCB

### Bottom layer
blue bottom silk layer PCB

### Combined top and bottom layer
PCB Mixed top and bottom

>  [!NOTE]
>  These designs were created entirely by us with the use of EasyEDA.
>  [Click here to go to their website and find out more](https://easyeda.com/)

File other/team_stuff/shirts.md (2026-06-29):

# We wanted to design some cool shirts - here's how it went!

### The first designs came along pretty quickly, one version advanced to the next when we cooperated to find the best design that we could all agree upon. We then seeked help from proffessionals in printing on clothes and fabrics to reach our final designs. All original designs where made using canva combined with free online source designs, and then altered with special software by the experts.

# **-SHIRTS-**
> ### design process from first to last design (Left is front, Right is back)









## **-PHOTO WITH SHIRTS-**

shirts back

# **-SWEATERS-**
> ### design process from first to last design (Left is front, Right is back)







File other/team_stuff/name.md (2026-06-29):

# **V I V A - Λ Α - V Ι Δ Α**

## Our name is essentially a word play on the famously known phrase *Viva La Vida*
> ### Meaning to "Live life"
## In greek, "Vida (Βίδα)" Literally means "a screw", completely changing the meaning of the phrase to us
> ### Now, it means "Long live the screw"

## We found this coincidence quite fitting, and when we changed up the letters to use both the Latin and Greek alphabets, we managed to create a name that -when capitalized- managed to use only straight lines and formed some very satisfying geometrical shapes.

## Letters used are as follows:

- ### Latin : VIVA _A VI_A
 
- ### Greek : _Ι_Α ΛΑ _ΙΔΑ
 
- ### Combined : VIVA ΛΑ VIΔΑ





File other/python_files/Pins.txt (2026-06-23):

front = pin27
left = pin17
right = pin22
Mosfet as switch = pin5

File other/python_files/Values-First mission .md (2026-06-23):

## PID

### loops further away-slower-safer
>
>Distance = 25cm
>
>kP = 0.8
>
>kD = 2.3
>
>Speed = 0.75
>

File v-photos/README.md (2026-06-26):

Vehicle's photos
====

## This directory contains 6 photos of the vehicle from every side:

### Top
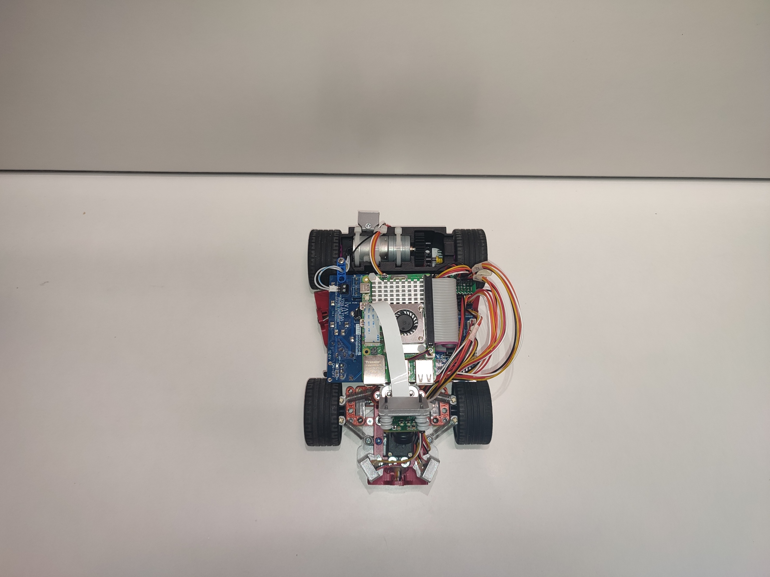
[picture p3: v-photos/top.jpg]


### Bottom
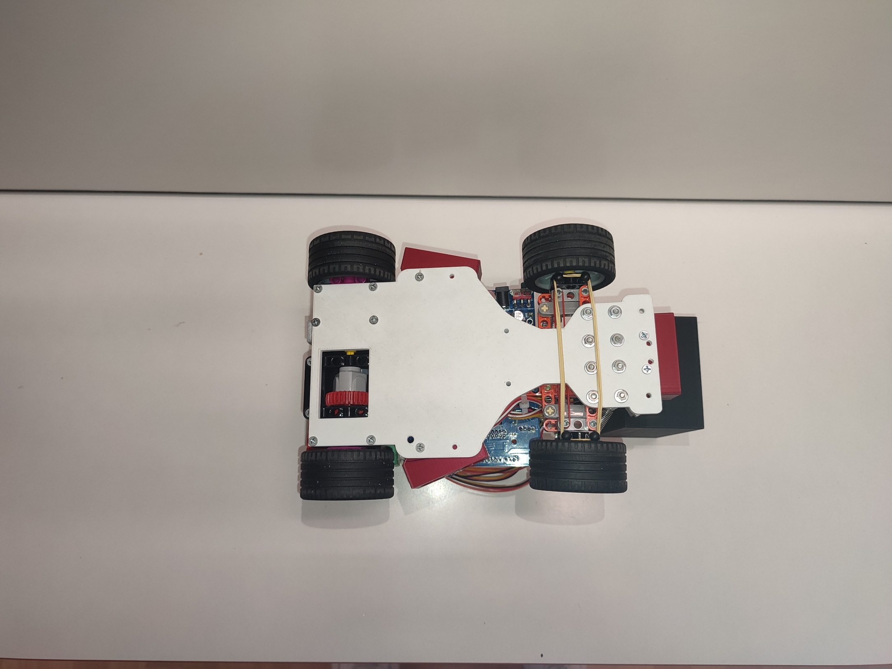
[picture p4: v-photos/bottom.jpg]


### Left
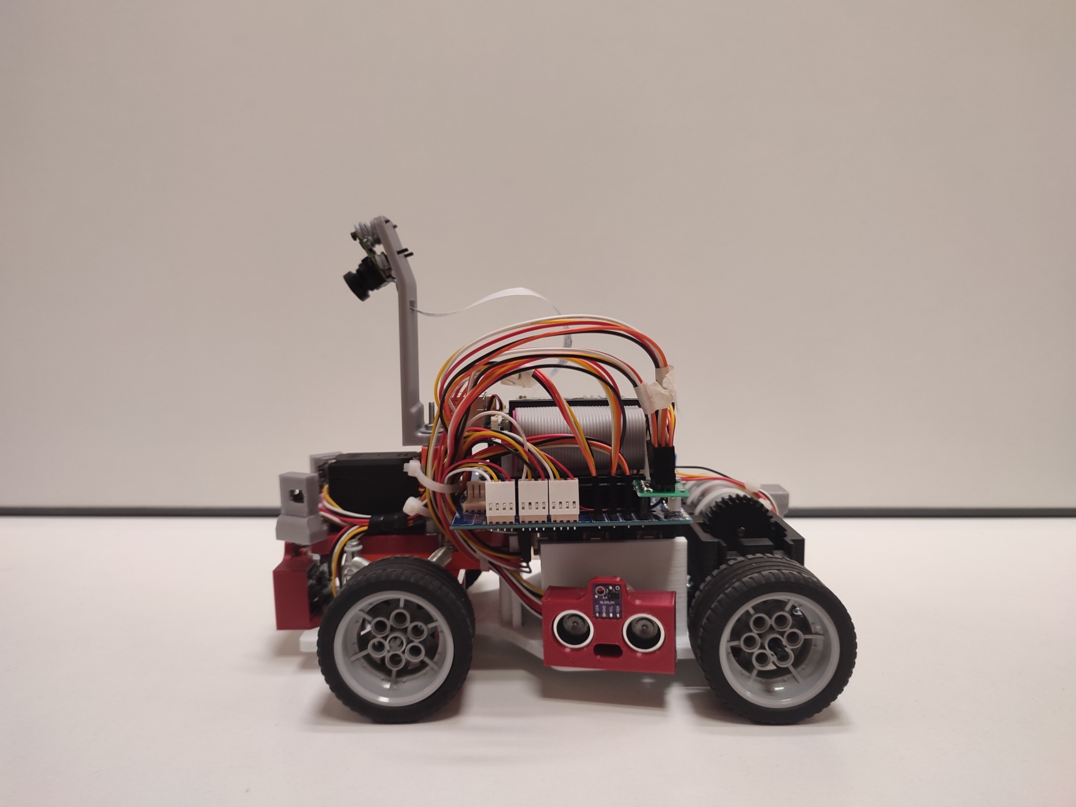
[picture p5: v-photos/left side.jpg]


### Right
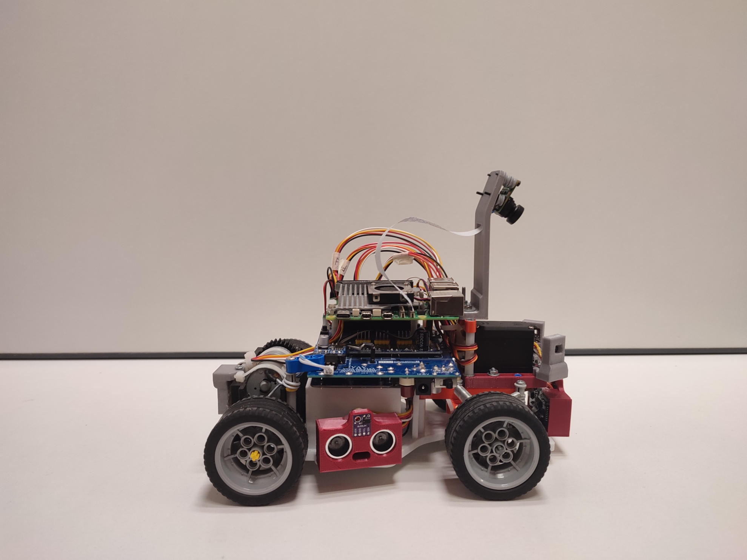
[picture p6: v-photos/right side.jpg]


### Front
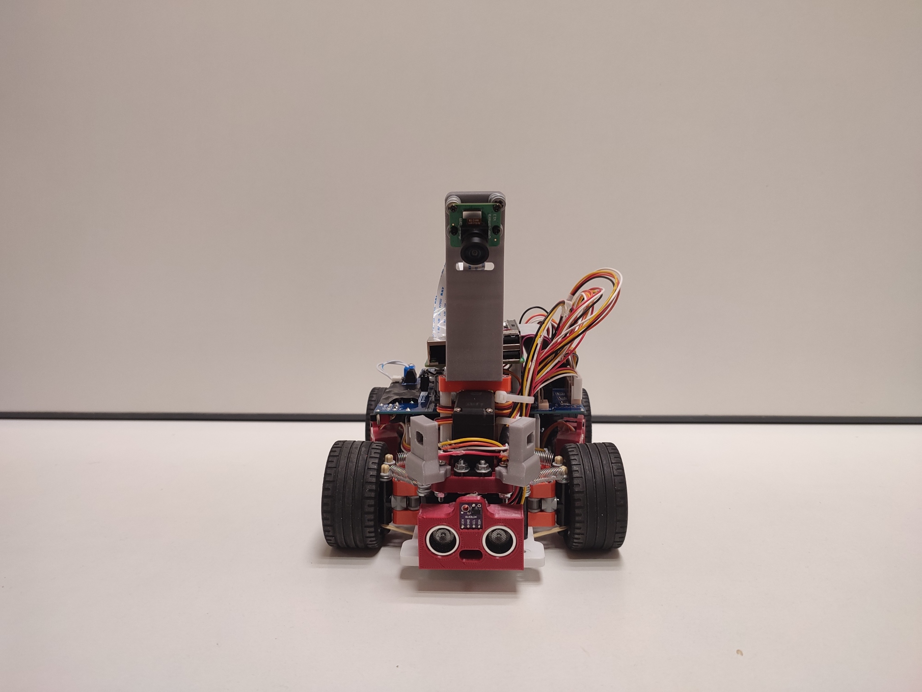
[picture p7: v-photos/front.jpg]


### Back
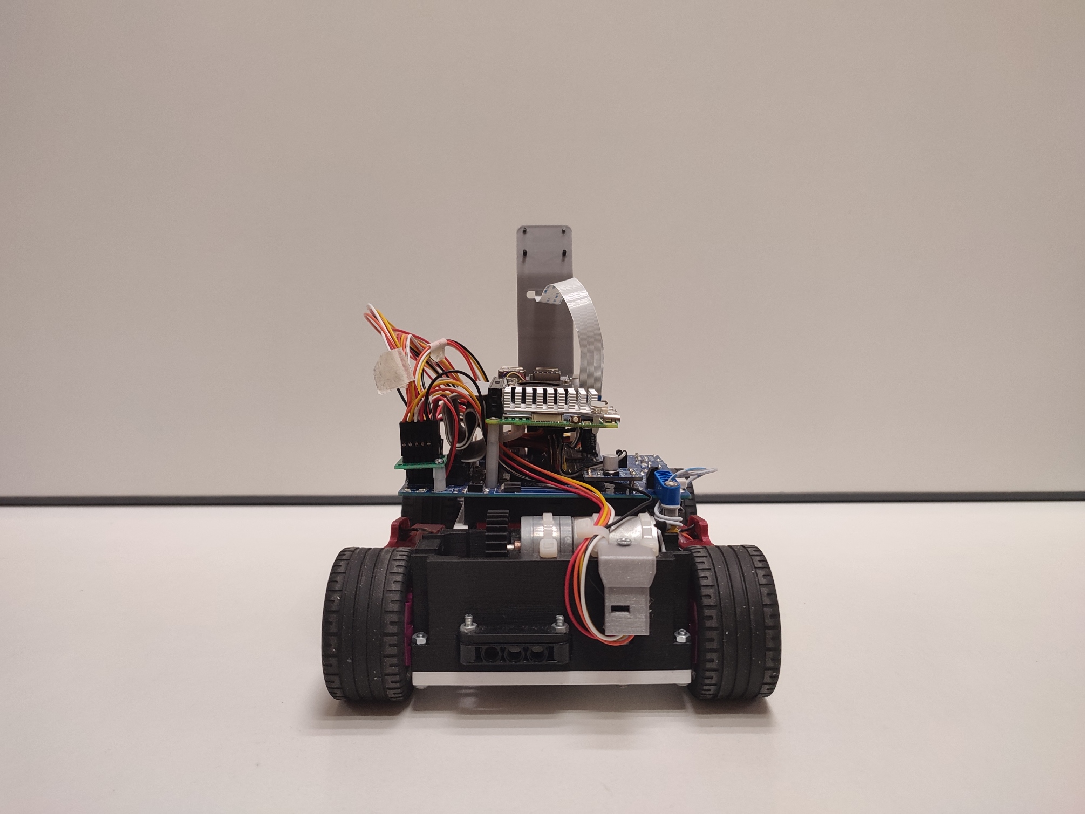
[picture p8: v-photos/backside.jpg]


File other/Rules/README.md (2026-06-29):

## These are the rules of future engineering category (2025) we were required to follow during these trials.
### They are imported above for purposes of easier replication and deeper understanding of our mission, additionally they can be found on the [WRO website](https://wro-association.org/wp-content/uploads/WRO-2025-Future-Engineers-Self-Driving-Cars-General-Rules.pdf).
<p align="center">
  
</p>

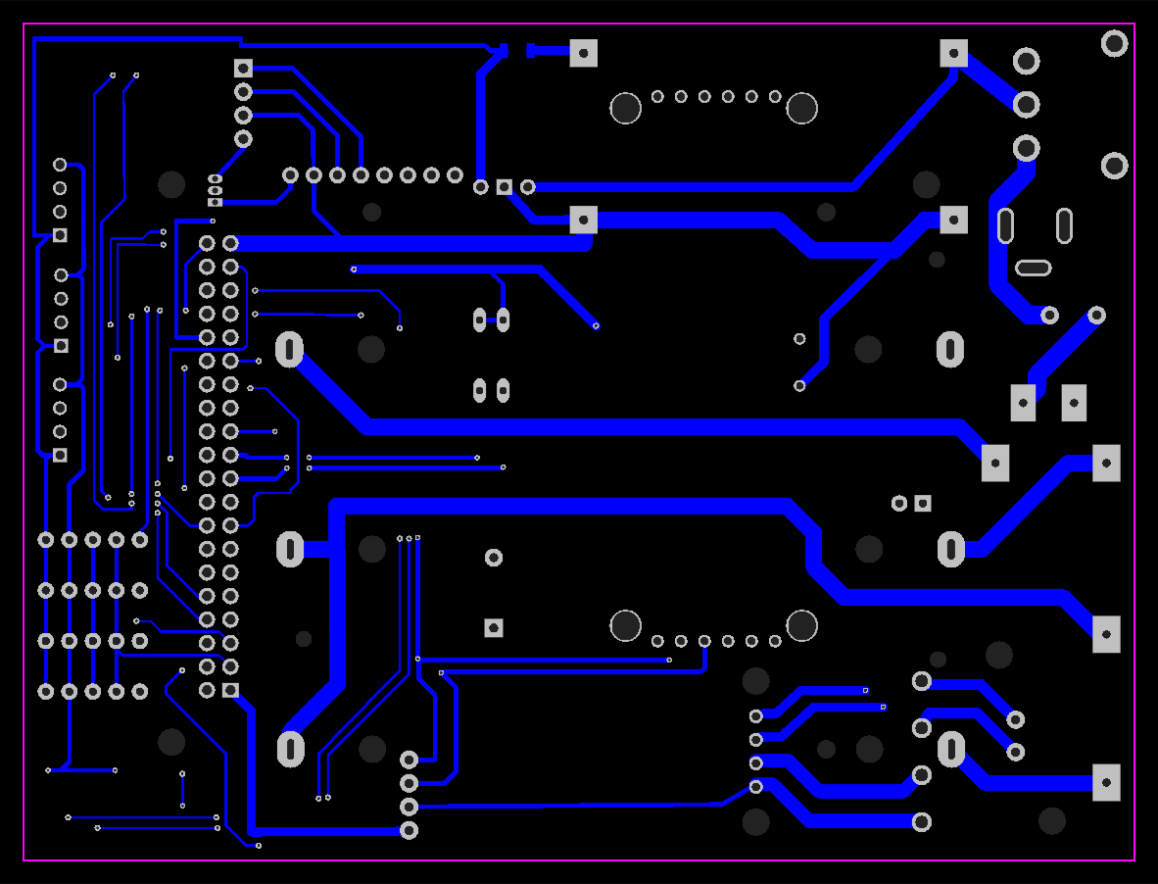
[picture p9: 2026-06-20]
schemes/PCB_Design/pcb_layout_bottom_layer.png

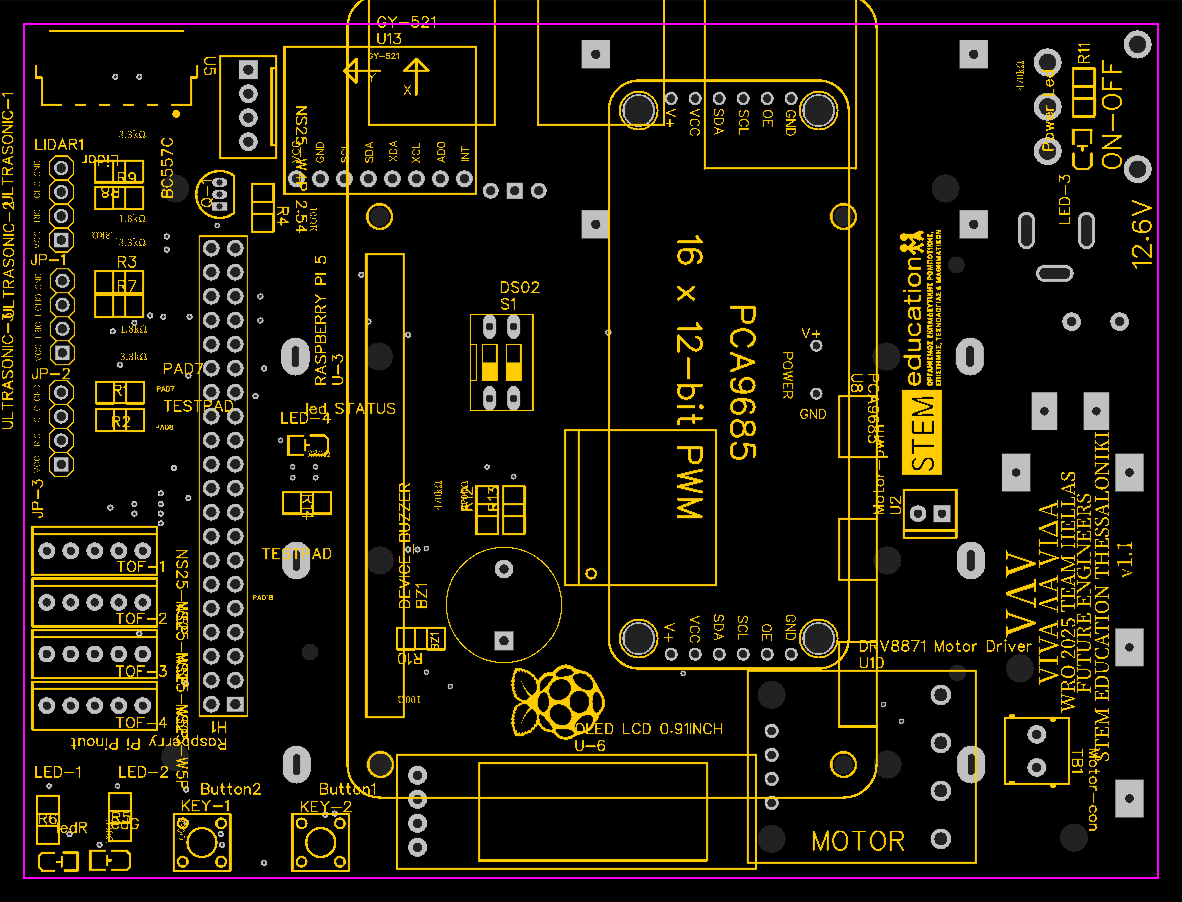
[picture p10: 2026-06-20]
schemes/PCB_Design/pcb_layout_top.png

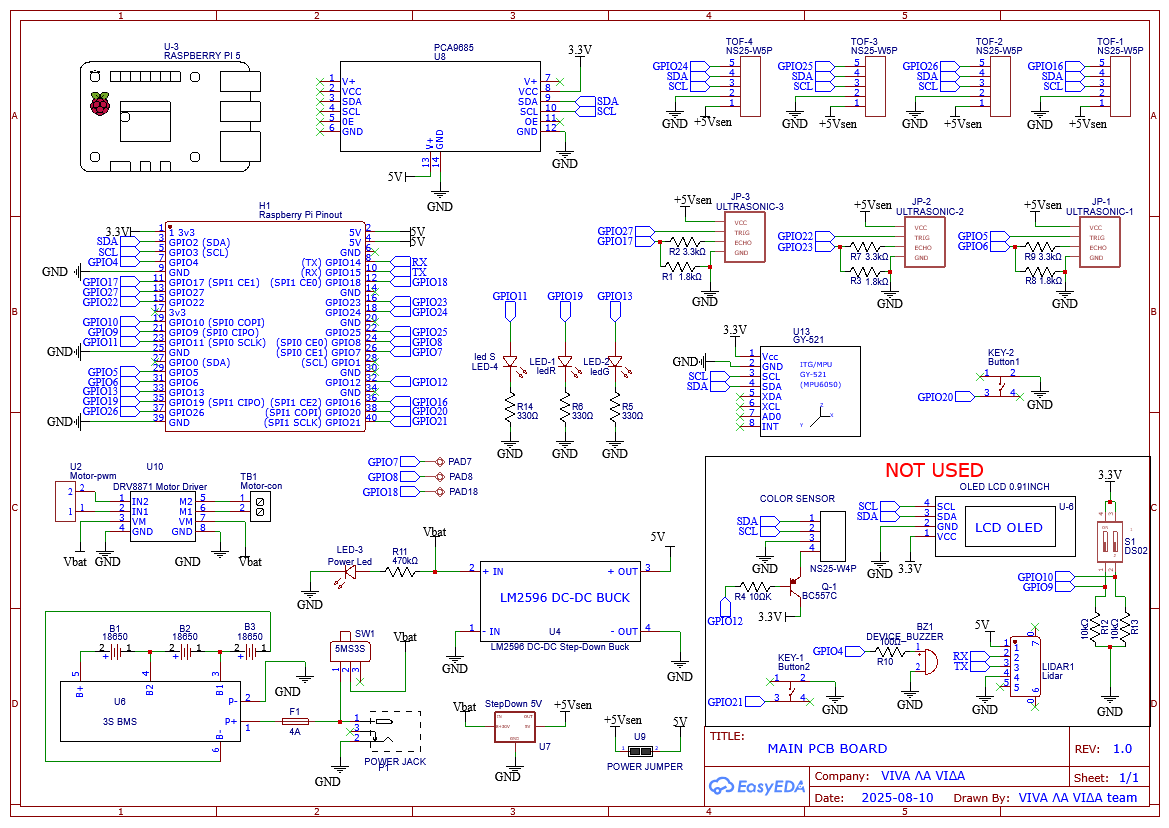
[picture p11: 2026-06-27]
schemes/Circuit_Diagram/Schematic_VIVA-LA-VIDA-PCB2_2026-06-27.png

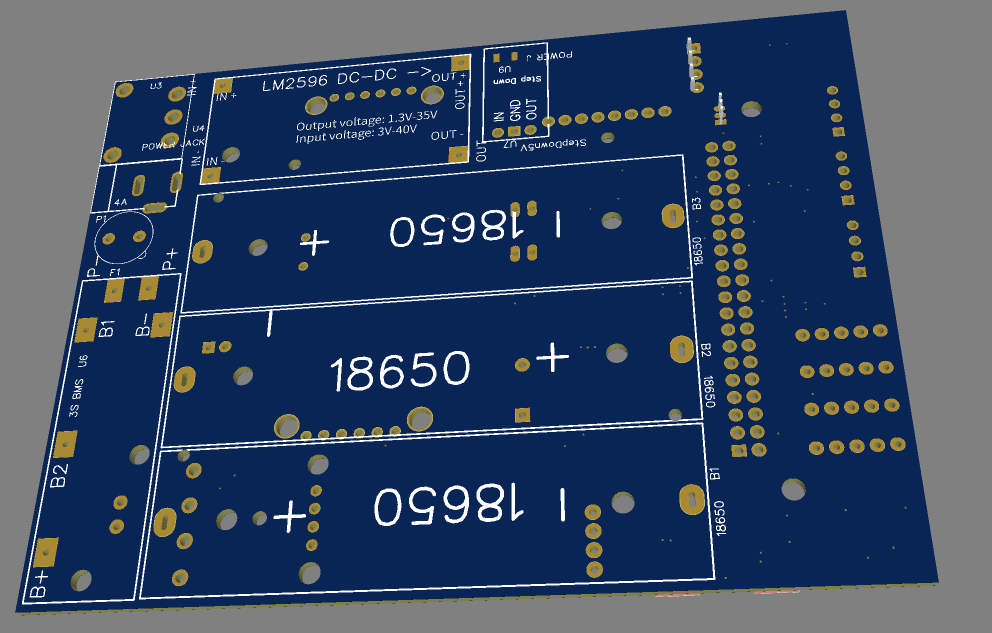
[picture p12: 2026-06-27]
schemes/PCB_Design/PCB_3D_back.png

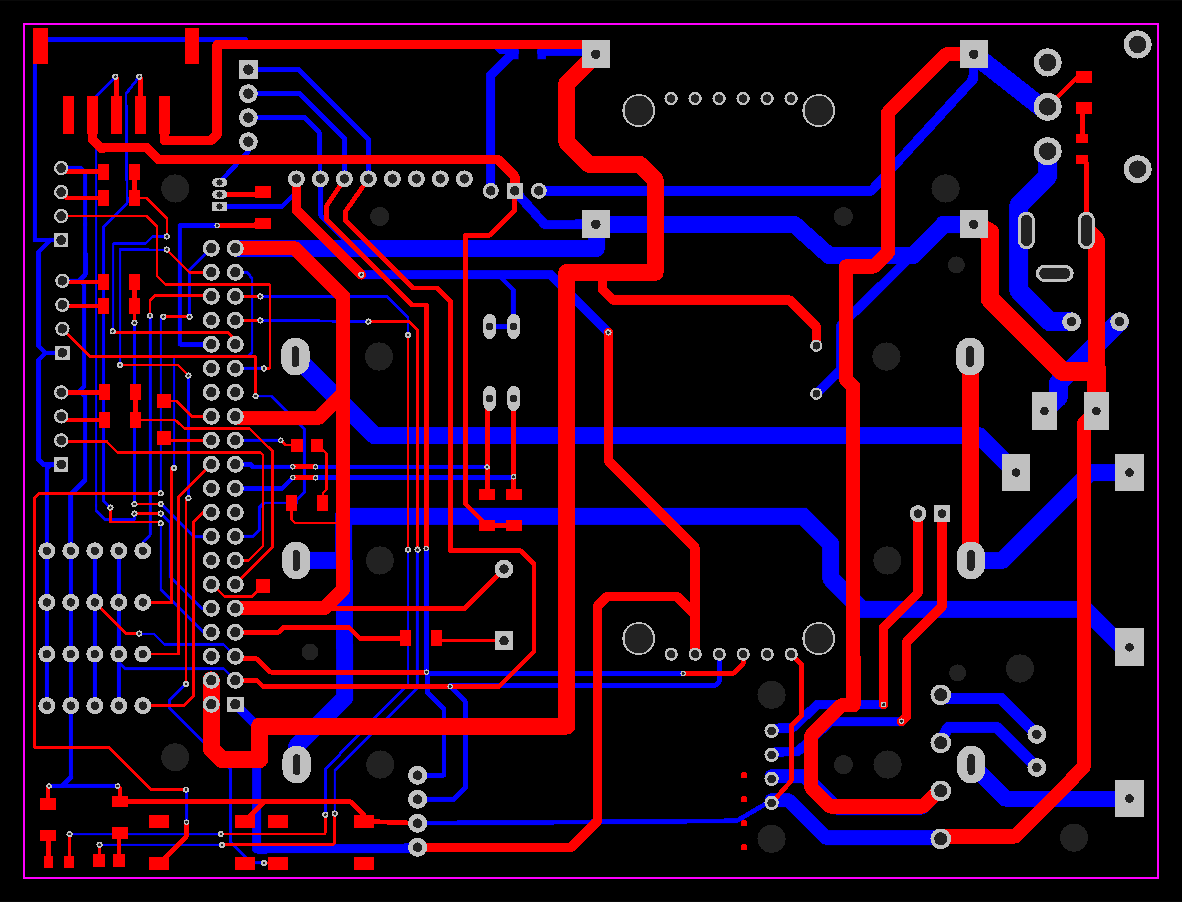
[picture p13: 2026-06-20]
schemes/PCB_Design/pcb_layout_combined_layer.png

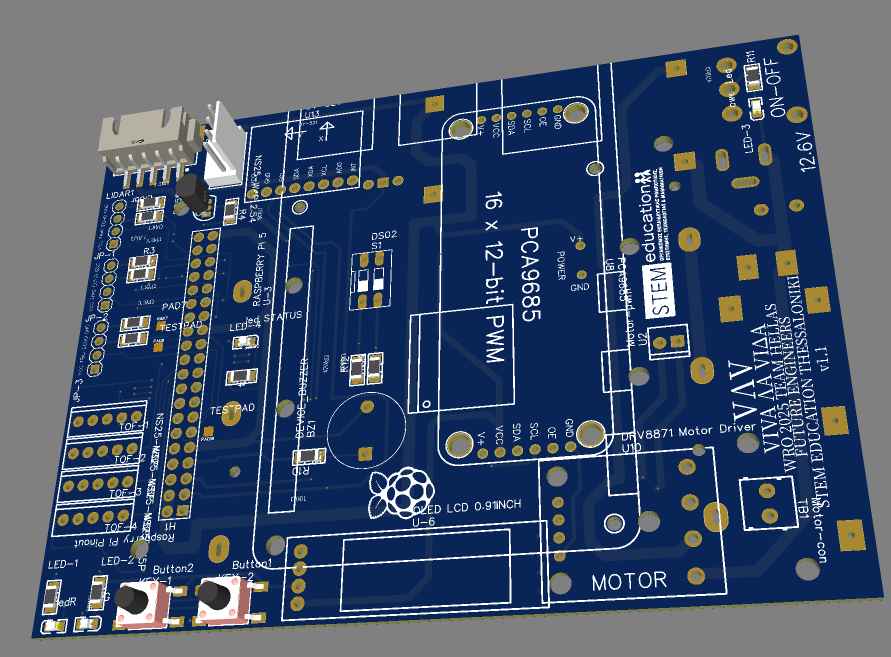
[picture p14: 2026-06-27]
schemes/PCB_Design/PCB_3D_front.png

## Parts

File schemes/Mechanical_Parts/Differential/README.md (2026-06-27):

## Differential – [Differential Model / Type]
The robot uses a **[differential model / type]** to split power from the drivetrain into independent left and right wheel motion. This differential allows the robot to turn smoothly by letting the wheels rotate at different speeds while still sharing a common input. As a result, it improves maneuverability on corners and reduces drivetrain stress compared to forcing the left and right sides to rotate at the same speed.



### 1 Differential Technical Specifications

**Mechanical Characteristics**
- Differential type: **[open / locked / limited-slip / gear differential / belt differential]**
- Input method: **[gear input / belt input / axle input]**
- Output method: **left/right outputs**
- Gear ratio: **[X:Y or X.xx:1]** (if applicable)
- Backlash / play: **[note, if known]**
- Intended wheel count/layout: **[e.g., 2-wheel output / 4-wheel layout]**

**Performance Characteristics**
- Expected turning behavior: **smooth differential turn**
- Torque transfer: **shared input → independent wheel speed**
- Benefits under load: **maintains traction while turning**

### 2 Why This Differential Was Chosen
1. **Smooth, controlled turning**  
   A differential lets the left and right sides rotate at different speeds during turns. This prevents one side from “fighting” the other, so the robot can arc through corners rather than scrubbing traction.

2. **Reduced drivetrain stress**  
   Because the wheels aren’t forced to match speed during steering, mechanical loads are lower. This helps reduce wear on drivetrain components during repeated cornering.

3. **Better traction and repeatability**  
   The robot maintains more consistent grip while following the controller’s intended path. That improves repeatability across runs, especially when turning under variable field friction.

4. **Straightforward integration**  
   The differential architecture is compatible with common drivetrain layouts:
   - shared input (from the motor)
   - separate left/right output paths to the wheel axles

### 3 Drivetrain and Power Integration
The differential is connected as follows:
- Motor output shaft → **differential input**
- Differential left output → **left wheel axle**
- Differential right output → **right wheel axle**

Advantages of this setup:
- Keeps power transfer centralized at the drivetrain input
- Allows turning behavior to come naturally from drivetrain kinematics (left/right speed divergence)
- Simplifies system tuning since turning is handled mechanically rather than relying entirely on software while the wheels fight each other

### 4 Alternative Drivetrain Approaches Considered
1. **Locked left/right drive (no differential)**  
   Pros: simpler mechanism  
   Cons: increases wheel scrub and mechanical stress; less smooth cornering

2. **Independent motors without differential (direct left/right control)**  
   Pros: software can command left/right speed explicitly  
   Cons: more tuning complexity; wheel slip can make behavior less predictable

3. **Chain/belt split without differential behavior**  
   Pros: packaging simplicity  
   Cons: still forces constraints between wheels, causing drag and uneven traction in turns

### Summary
The **[differential model/type]** provides the best combination of smooth cornering, reduced mechanical stress, and reliable drivetrain behavior. It enables correct turning by allowing left and right wheel speeds to diverge when required, producing more repeatable motion under field conditions.



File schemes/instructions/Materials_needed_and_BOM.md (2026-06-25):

| Material | Amount | Price in Euros |
|---|---|---|
| Raspberry Pi 5 8GB | 1 | 96.50 |
| Raspberry Pi Micro SD Card 64GB | 1 | 9.50  |
| Active Cooler for Raspberry Pi 5 | 1 | 6.40  |
| Camera Arducam IMX219 fisheye lens | 1 | 18.92 |
| PCB Prototype* | 5 | 26.25 | Note - Could only order a minimum of 5. Only 1 is needed
| Battery Holder 1x18650 for PCB | 3 | 2.70  |
| Li-ion Battery Charger Protection Module | 1 | 3.40  |
| Fuse 4A | 1 | 0.71  |
| Main power switch | 1 | 2.23  |
| DC Power Jack 5.5 x 2.1mm | 1 | 0.20  |
| Converter Step-Down LM2596S | 1 | 2.90  |
| Ultrasonic Sensor HC-SR04 | 3 | 5.40  |
| Laser Sensor - VL53L0X | 6 | 28.80 |
| Triple Axis Gyroscope & Accelerometer MPU6050 | 1 | 3.60  |
| Metal Gearmotor 25mm - 210RPM 9-12V | 1 | 6.80  |
| DC Motor Driver Board DRV8871 | 1 | 10.80 |
| Standard Servo with Metal Gear MG996R | 1 | 8.90  |
| 16-Channel 12-bit PWM/Servo Driver - PCA9685  | 1 | 6.80  |
| Tact Switch 6x6mm 7mm - SMD | 1 | 0.08  |
| Battery Lithium 18650 3.6V 3400mAh | 3 | 17.40 |
| Jumper Wires 30cm 5 Pin | 6 | 2.50  |
| Molex KF2510 Jumper Wire 4 Pin | 3 | 1.20  |
| IDC Connector 2x20 Pin Male | 1 | 0.45  |
| GPIO Ribbon Cable for Raspberry Pi 40P | 1 | 2.00  |
| Led 0805 SMD Clear | 3 | 0.36  |
| Resistor SMD 0805 1/8W | 12 | 0.24  |
| Flexible Flat Cable 0.5mm 22 Pin | 1 | 2.90  |
| M2 Plastic F/F L20mm | 2 | 0.30  |
| M2×8mm | 8 | 0.47  |
| M3×12mm flat head | 2 | 0.11  |
| M3×16mm flat head | 20 | 1.15  |
| M3×20mm flat head | 14 | 0.97  |
| M3×30mm flat head | 2 | 0.15  |
| M3×50mm | 2 | 0.70  |

> [!NOTE]
> About PCB prototype - Could only order a minimum of 5. Only 1 is needed

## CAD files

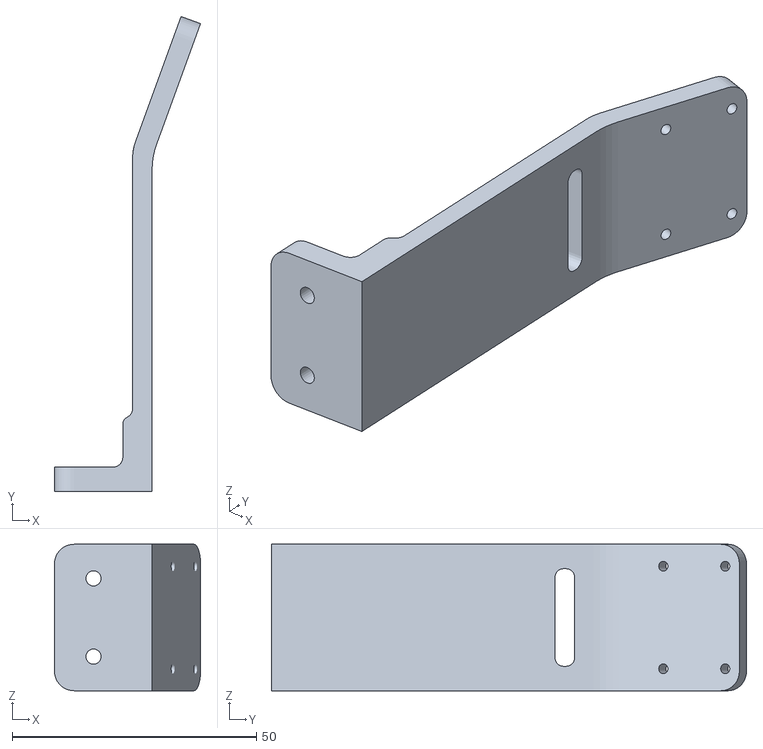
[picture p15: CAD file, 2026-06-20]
models/3d_designs/VLV-camerabase-final.stl
29.9 x 97.3 x 30.0

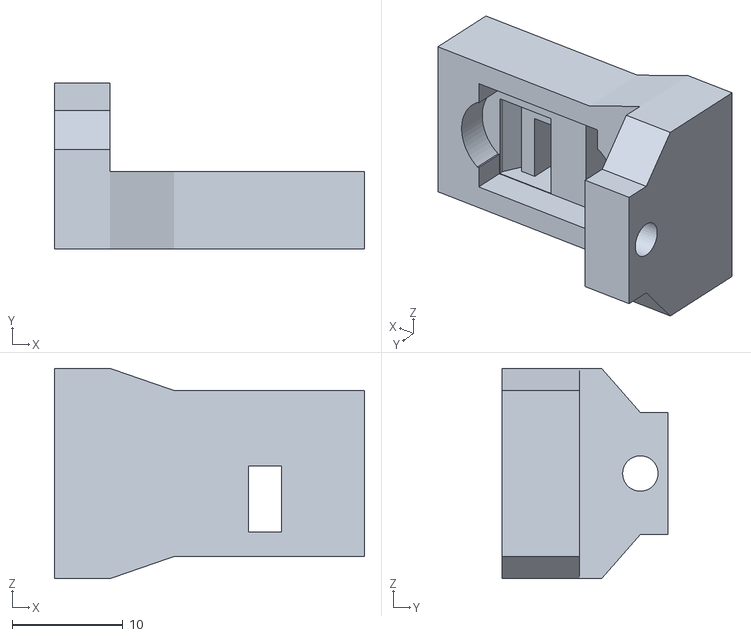
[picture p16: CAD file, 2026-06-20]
models/3d_designs/VLV-Tof-final.stl
28.0 x 15.0 x 19.0

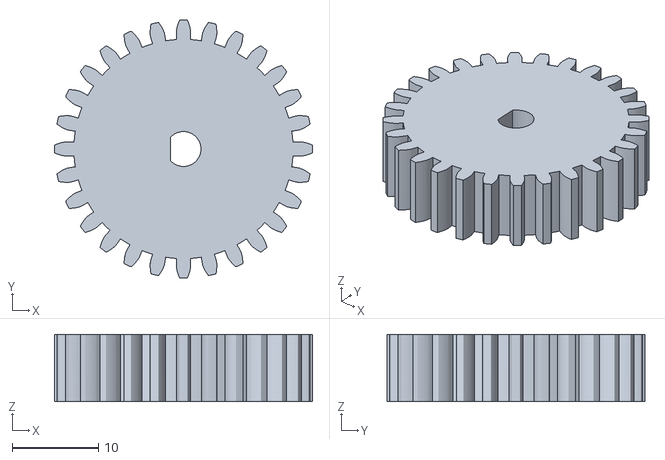
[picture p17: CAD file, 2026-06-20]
models/3d_designs/VLV-motorgear-final.stl
30.0 x 30.0 x 7.80

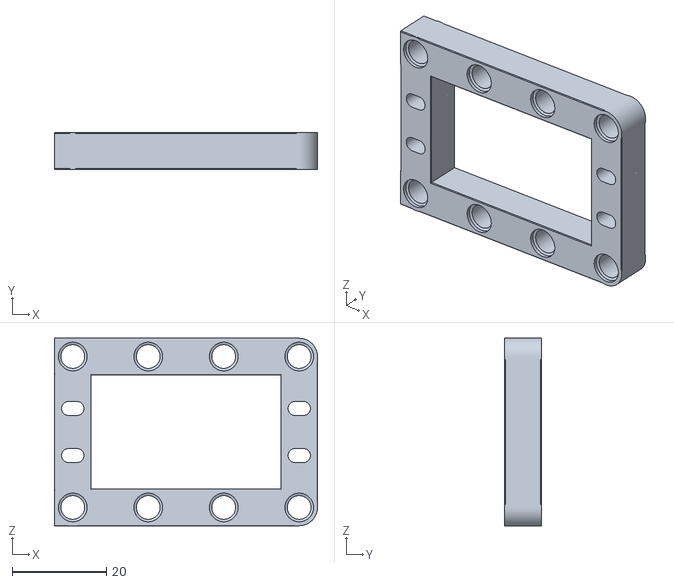
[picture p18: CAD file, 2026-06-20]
models/3d_designs/VLV-servoholder-final.stl
55.8 x 7.75 x 39.8

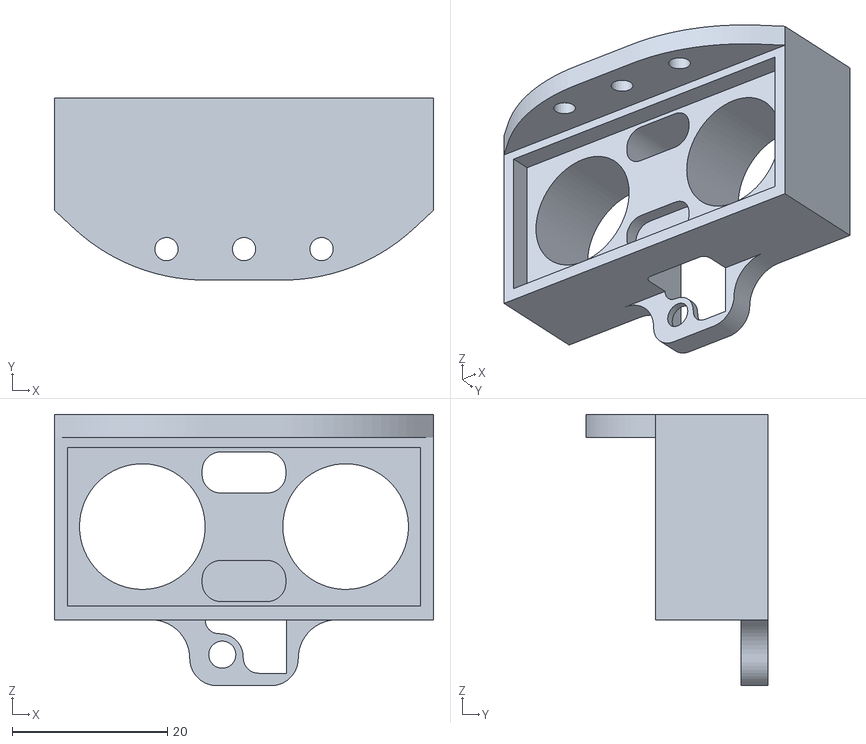
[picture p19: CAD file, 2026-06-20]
models/3d_designs/VLV-disensorbase-final.stl
48.9 x 23.5 x 35.0

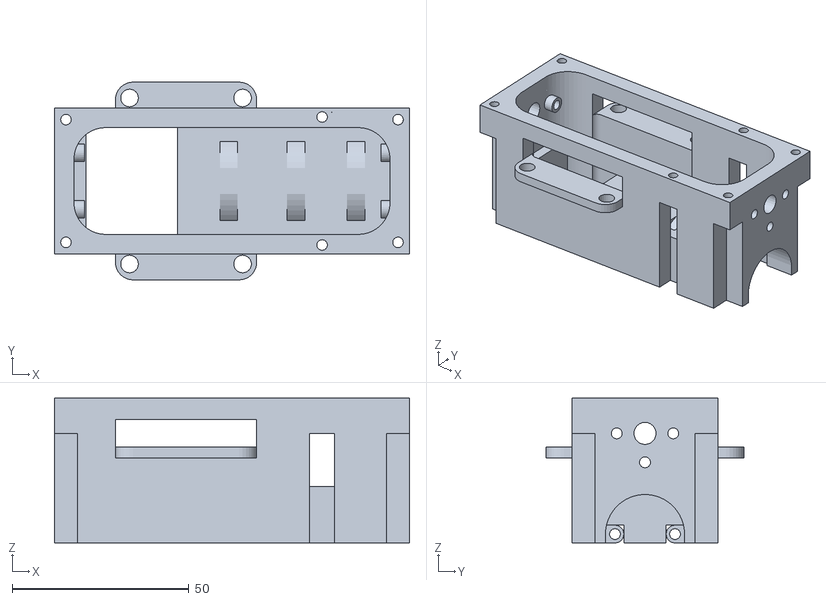
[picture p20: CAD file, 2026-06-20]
models/3d_designs/VLV-motorbase-final.stl
100.5 x 56.0 x 41.0

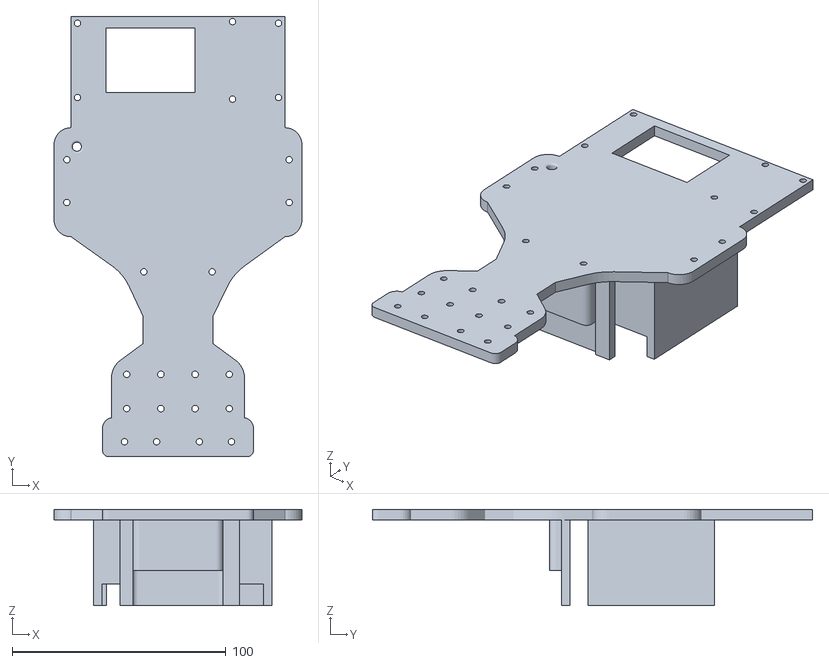
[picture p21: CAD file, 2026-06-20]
models/3d_designs/VLV-chassis-final.stl
116.0 x 206.0 x 45.0

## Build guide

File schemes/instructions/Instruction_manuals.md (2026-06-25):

# Bellow you will find the annotated photo instructions to re-connect our robot from scratch

> [!IMPORTANT]
> ## Before opening the manual, ensure you have all the necessary [equipment and materials](https://github.com/VIVA-LA-VIDA-Hellas/VIVA-LA-VIDA_2/blob/main/models/instructions/Materials%20needed%20and%20BOM.md), and have prepared the [Lego ackerman](https://github.com/VIVA-LA-VIDA-Hellas/VIVA-LA-VIDA_2/blob/main/models/instructions/lego_ackermann_instructions.md) and [Lego differential](https://github.com/VIVA-LA-VIDA-Hellas/VIVA-LA-VIDA_2/blob/main/models/instructions/lego_differential_instructions.md). If you do not have all materials and/or the lego parts have not yet been built, you will be unable to finish following these instructions.

## [Instruction manual.pdf](https://github.com/user-attachments/files/23657641/INSTRUCTION.MANUAL.pdf) <-
### [Instruction manual online link](https://acrobat.adobe.com/id/urn:aaid:sc:EU:a7705abf-189d-4e17-b0d9-b81a8bd3fbde) <-

> Good luck building!

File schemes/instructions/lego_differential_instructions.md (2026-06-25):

# LEGO differential instructions - How to recreate the differential on our robot car

### [Lego differential instructions.pdf](https://github.com/user-attachments/files/23562968/Lego.differential.instructions.pdf)
 [Lego differential instructions online link](https://acrobat.adobe.com/id/urn:aaid:sc:EU:bf6a4edf-ee3a-4b8f-b326-477fbbe929c4)

## Parts needed:

differential parts

> [!TIP]
> Ensure you have all necessary parts before beginning construction

## Construct the Differential System

Assemble the differential system using the **motor base, DC motor, motor gear**, and several **LEGO parts**, along with **tie-ups** and **screw**s to secure everything in place.

Firstly take the motor base and the **lego technic liftarm (64179)** (photo1).
Insert the lego part through the hole shown in (photo2). 
The outcome should be similar to the one shown in (photo3).

1 (2)
2 (2)
3 (2)

Turn the structure upside down and add the **lego gear box** consisting of the 6 lego parts (1x 65414,1x 65413,4x 6589) (photo4)
Connect the the gear box to the motor base using the 2 axles: use the longer in the right side and the smaller one in the left
For extra steadiness use lego end stops (you can use the ones given to you) (photo5)

4 (2)
5 (2)

Take the two "biscuit" lego parts and grab yourself some **screws(3x12)**, a screw driver and a plier (photo6.1)
Tight the 3 screws as shown in the picture below (photo6.2)




Do the same thing in the other side, the outcome should be identical (or at least similar) to the one in the photo below 



In this step, we actually need the [motor](https://grobotronics.com/metal-gearmotor-25mm-210rpm-9-12v.html) and some tire-ups
After you connect the the motor to the base as shown in (photo8).
For extra stability pass the tire-ups through the holes that are specifically made for them that are shown in pictures 8,9 (photo8),(photo9) and tighten them up.




Grab the 3d printed motor gear and attach it to the motor (photo10)



If you want to achieve the maximum reagarding the stability of the structure, get some extra screws and nuts and affix them to the construction as shown in the pictures below (photo11)



Have the steps been completed succesfully, the differnetial system is ready.
In order to link it with the rest of the chassis you need 6 screws (1 screw for each hole in the chassis)
Note: the holes of the two parts (motor base and chassis) should be allined. If not try relocating the screws
Consult the pitcure below for the connection of the two parts (photo12)



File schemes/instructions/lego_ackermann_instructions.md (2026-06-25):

# LEGO ackerman instructions - How to recreate the ackerman on our robot car

### [Lego ackerman instructions.pdf](https://github.com/user-attachments/files/23562926/Lego.ackerman.instructions.pdf)
 [Lego ackerman instructions online link](https://acrobat.adobe.com/id/urn:aaid:sc:EU:f2392e2a-f047-4426-ba8e-89044fcd8d48)

## Parts needed:
ackerman parts 2
ackerman parts 1

> [!TIP]
> Ensure you have all necessary parts before beginning construction

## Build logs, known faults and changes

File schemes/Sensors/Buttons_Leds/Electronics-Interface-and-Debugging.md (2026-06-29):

# Interface and Debugging

The robot includes a set of simple but effective user-interface components designed to support fast testing, clear diagnostics, and reliable operation during competition. These elements help the operator understand the robot’s current state without needing a laptop or external monitor.

---

## 1 Purpose of On-Robot Interface Elements

The interface system provides:

- **Immediate visual feedback** on mode and state  
- **Simple on-device control** without SSH or remote tools  
- **Operational clarity** during competition setups  
- **Fast debugging** when diagnosing navigation or sensor issues  

These features significantly reduce testing time and improve repeatability.

---

## 2 LED Indicators (Status + Debug)

Several LEDs are connected directly to Raspberry Pi GPIO pins.

### Roles of the LEDs:

- **State indication:** cruising, turning, obstacle detected  
- **Lap progression:** LED patterns can represent which lap (1–3) the robot is currently completing  
- **Error signaling:** fast blinking or fixed patterns can indicate sensor failure, IMU freeze, or ToF timeout  
- **Startup sequence:** green LED ready state, red LED indicates system initialization  

### Engineering Notes:

- LEDs are driven through **current-limiting resistors** to protect GPIO pins  
- GPIO selection avoids pins used by I²C/SPI/UART or reserved functions  
- LEDs can be multiplexed or repurposed easily in software for new states  

This lightweight indicator system makes the robot significantly easier to operate without external equipment.

---

## 3 Physical Buttons (Start/Stop Control)

The robot includes tactile push-buttons wired to safe GPIO inputs.

### Button Functions:

- **Start/Run button:** launches the main autonomous routine  
- **Stop/Safe-reset button:** immediately halts motors and resets state  
- **Extra “NOT USED” footprint:** left intentionally for future upgrades (e.g., mode switching, manual override, calibration triggers)

### Engineering Notes:

- Buttons use **pull-up or pull-down resistors** for stable logic levels  
- Debouncing is handled in software (edge detection + delay filter)  
- Buttons allow full control even if SSH, Wi-Fi or GUI is unavailable  

Physical buttons ensure reliable interaction during practice and competition rounds.

---

## 4 Benefits of This Interface Design

- **Zero-laptop operation:** robot can be tested on field with no external devices  
- **Fast feedback:** operator instantly knows what the robot perceives or is doing  
- **Low complexity:** minimal components, low power, high reliability  
- **Future-proofing:** extra pads allow additional buttons, LEDs, or display modules  

---

## 5 Alternative Interface Options Considered

### 1. OLED or LCD Display
- **Pros:** rich debug information, text menus  
- **Cons:** more wiring/space; not needed for WRO where setup time is short  

### 2. Bluetooth or Wi-Fi App-Based Control
- **Pros:** flexible, remote debugging  
- **Cons:** wireless latency, potential interference during competition  

### 3. Rotary encoders or DIP switches
- **Pros:** physical mode selection  
- **Cons:** unnecessary complexity for a small autonomous robot  

### 4. RGB LED bar or NeoPixel strip
- **Pros:** expressive color-coded states  
- **Cons:** requires more power and precise timing  

---

## Summary

The robot’s interface system uses **simple LEDs and buttons** to provide reliable, low-cost, competition-friendly debugging and control. The design supports ease of use, quick iteration, and clear feedback while maintaining spare capacity for future enhancements.

---

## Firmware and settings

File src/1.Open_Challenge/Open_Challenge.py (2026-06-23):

#-----------------------------------------------------------------------------------------------------------------------
# 1st Mission WRO 2025 FE - VivaLaVida
# Final Version
#-----------------------------------------------------------------------------------------------------------------------

# ===============================
# IMPORTS                       
# ===============================


import os, sys

VENV_PY = "/home/stem/env/bin/python"  # exact path to Python in your venv

if sys.executable != VENV_PY and os.path.exists(VENV_PY):
    print(f"[INFO] Relaunching under virtual environment: {VENV_PY}", flush=True)
    os.execv(VENV_PY, [VENV_PY] + sys.argv)

# --- your normal robot code below ---
print(f"[INFO] Now running inside: {sys.executable}")


import threading
import time
from collections import deque
import busio
from adafruit_pca9685 import PCA9685
import adafruit_mpu6050
import csv
from datetime import datetime
import json

import board
import digitalio
import adafruit_vl53l0x
from enum import Enum, auto
import numpy as np
from gpiozero import Device
from gpiozero.pins.lgpio import LGPIOFactory   # Uses /dev/gpiochip*
Device.pin_factory = LGPIOFactory()
from gpiozero import Button, LED
from gpiozero import DistanceSensor
from threading import Event

BASE_DIR = os.path.dirname(os.path.abspath(__file__)) # Get directory of the running script
CONFIG_FILE = os.path.join(BASE_DIR, "1st_mission_variables_SAFE.json")

# ===============================
# CONFIGURATION VARIABLES
# ===============================

# ---------- Initialization ----------
USE_GUI = 0                   # 1 = Debugging mode (run with GUI), 0 = COMPETITION MODE (run headless, no GUI)
DEBUG = 0                     # 1 = enable prints, 0 = disable all prints
USE_TOF_SIDES = 0             # Side sensors:  0 = Ultrasonic, 1 = ToF
USE_TOF_FRONT = 0             # Front sensor:  0 = Ultrasonic, 1 = ToF
USE_TOF_CORNERS = 0           # Front side sensor: 0 = disable, 1 = enable

NARROW_SUM_THRESHOLD = 60     # cm; left+right distance threshold to decide if in between narrow walls
NARROW_HYSTERESIS = 10        # cm; prevents rapid toggling
NARROW_FACTOR_SPEED = 0.6     # multiply state speeds when in narrow corridors
NARROW_FACTOR_DIST  = 0.5     # multiply distance-based thresholds/corrections when in narrow corridors

# ---------- Speeds ----------
SPEED_IDLE = 0
SPEED_STOPPED = 0
SPEED_CRUISE = 24             # Motor speed for normal straight driving (0-100%)
SPEED_TURN_INIT = 16          # Motor speed while waiting for open side to turn
SPEED_TURN = 24               # Motor speed while turning
SPEED_POST_TURN = 24          # Motor speed following a turn

# ---------- Driving ----------
SOFT_MARGIN = 26              # Distance from wall where small steering corrections start (cm)
MAX_CORRECTION = 7            # Maximum servo correction applied for wall-following (degrees)
CORR_EPS = 1.5                # cm: treat the side as "steady" if within ±1.5 cm of trigger value
CORRECTION_MULTIPLIER = 1.4   # Proportional gain (servo degrees per cm of error 0 default: 2). Higher = snappier; lower = smoother&slower. 

STOP_THRESHOLD = 20           # Front distance (cm) at which robot stops immediately
OBSTACLE_WAIT_TIME = 5.0      # seconds to wait before retrying after a front-stop

# ---------- Turn management ----------
FRONT_TURN_TRIGGER = 90       # Front distance (cm) at which a turn is triggered
TURN_DECISION_THRESHOLD = 80  # Minimum side distance (cm) to allow turn in that direction
TURN_ANGLE_LEFT = 61          # Servo angle for left turn
TURN_ANGLE_RIGHT = 119        # Servo angle for right turn
TURN_TIMEOUT = 2.5            # Maximum time allowed for a turn (seconds)
TURN_LOCKOUT = 1.5            # Minimum interval between consecutive turns (seconds)
POST_TURN_DURATION = 0.5      # Time to drive straight after a turn (seconds)
LOCK_TURN_DIRECTION = 1       # 1 = enable turn lock direction after 1st turn, 0 = disable
TARGET_TURN_ANGLE = 86        # Degrees to turn per corner
TURN_ANGLE_TOLERANCE = 6      # Acceptable overshoot (degrees)

# ---------- Turn angle constraints ----------
MIN_TURN_ANGLE = 75           # Minimum yaw change (degrees) before turn can stop
MAX_TURN_ANGLE = 105          # Maximum yaw change (degrees) to force stop turn

# ---------- Laps ----------
MAX_LAPS = 3                  # Maximum number of laps before stopping (0 = unlimited)
POST_LAP_DURATION = 2.50         # Time to drive forward after final lap before stopping (seconds)

# ---------- Sensor data filtering ----------
N_READINGS = 4                # Number of readings stored for median filtering
US_QUEUE_LEN = 1              # Queue_len for Ultrasonic gpiozero.DistanceSensor
FILTER_ALPHA = 1.0            # Ultrasonic 0.1 = smoother, 0.5 = faster reaction, 1 to ignore filter
FILTER_JUMP = 9999            # Ultrasonic maximum jump (cm) allowed between readings
FILTER_ALPHA_TOF = 1.0        # ToF 0.1 = smoother, 0.5 = faster reaction, 1 to ignore filter
FILTER_JUMP_TOF = 9999        # ToF maximum jump (cm) allowed between readings

US_MAX_DISTANCE_FRONT = 2.0  # Ultrasonic front max read distance
US_MAX_DISTANCE_SIDE = 1.2   # Ultrasonic side max read distance

# ---------- Loop timing ----------
LOOP_DELAY = 0.005            # Delay between main loop iterations (seconds) 0.02
SENSOR_DELAY = 0.005          # Delay between sensor reads

#-----------------------------------------------------------------------------------------

# ---------- Plotting ----------
MAX_POINTS = 500               # Maximum number of points to store for plotting

RAD2DEG = 180.0 / 3.141592653589793

# --- I2C concurrency guard ---
I2C_LOCK = threading.Lock()

def dprint(*args, **kwargs): #Conditional print — only prints when DEBUG == 1.
    if DEBUG:
        print(*args, **kwargs)

# --- Headless-safe placeholders for GUI symbols ---
slider_vars = {}
btn_readings = btn_start = btn_stop = None
lbl_turns = lbl_laps = None
root = canvas = None

# ===============================
# LOAD VARIABLES FROM JSON (if exists)
# ===============================

def load_variables_from_json(path=CONFIG_FILE): # Override defaults with values from JSON if the file exists.
    if not os.path.exists(path):
        print("⚙️ No external config found — using built-in defaults.")
        return
    try:
         with open(path, "r") as f:
              data = json.load(f)
         count = 0
         for k, v in data.items():
             if k in globals():
                 globals()[k] = v
                 count += 1
         print(f"✅ Loaded {count} variables from {os.path.basename(path)}")
    except Exception as e:
         print(f"[ERROR] Config load failed: {e} — using built-in defaults.")

load_variables_from_json() # Call it right after defining defaults so everything below sees the overrides

if os.environ.get("DISPLAY", "") == "": # If there is no X server, force headless regardless of config
    USE_GUI = 0

def norm180(a: float) -> float: # Normalize angle to [-180, 180)
    return (a + 180.0) % 360.0 - 180.0

def snap90(a: float) -> float: # Nearest multiple of 90° (…,-180,-90,0,90,180,…)
    return round(a / 90.0) * 90.0

# --- Store immutable base values for scaling ---
BASE_SPEED_IDLE        = SPEED_IDLE
BASE_SPEED_STOPPED     = SPEED_STOPPED
BASE_SPEED_CRUISE      = SPEED_CRUISE
BASE_SPEED_TURN_INIT   = SPEED_TURN_INIT
BASE_SPEED_TURN        = SPEED_TURN
BASE_SPEED_POST_TURN   = SPEED_POST_TURN

BASE_MAX_CORRECTION     = MAX_CORRECTION
BASE_FRONT_TURN_TRIGGER = FRONT_TURN_TRIGGER
BASE_STOP_THRESHOLD     = STOP_THRESHOLD

# --- Global factors (automatically updated) ---
SPEED_ENV_FACTOR = 1.0
DIST_ENV_FACTOR  = 1.0  # for distance-related thresholds

# --- Helper functions to get "effective" (scaled) values ---
def eff_soft_margin(): #Return scaled soft margin distance (cm) for gentle steering corrections
    return int(SOFT_MARGIN * DIST_ENV_FACTOR)

def eff_max_correction(): #Return scaled maximum steering correction (degrees)
    return max(1, int(MAX_CORRECTION * DIST_ENV_FACTOR))

def eff_front_turn_trigger(): #Return scaled front distance threshold (cm) for initiating a turn
    return int(FRONT_TURN_TRIGGER * DIST_ENV_FACTOR)

def eff_stop_threshold(): #Return scaled front distance threshold (cm) for immediate stop
    return int(STOP_THRESHOLD * DIST_ENV_FACTOR)

# --- Scaled state speeds ---
def state_speed_value(state_name: str) -> int:
    base = {
        "IDLE":      SPEED_IDLE,
        "STOPPED":   SPEED_STOPPED,
        "CRUISE":    SPEED_CRUISE,
        "TURN_INIT": SPEED_TURN_INIT,
        "TURNING":   SPEED_TURN,
        "POST_TURN": SPEED_POST_TURN,
    }.get(state_name, SPEED_CRUISE)
    return int(base * SPEED_ENV_FACTOR)

def headless_toggle_pause(): #Toggle pause/resume of the driving loop in headless mode
    global paused_by_button, status_text
    if loop_event.is_set(): #Pause
        loop_event.clear()
        paused_by_button = True
        robot.stop_motor()
        robot.set_servo(SERVO_CENTER)
        RED_LED.off()     # paused
        GREEN_LED.on()
        status_text = "Paused (button)"
    else:  # RESUME
        paused_by_button = False
        loop_event.set()
        GREEN_LED.off()   # running
        RED_LED.on()
        status_text = "🚗 Resumed"

# ===============================
# HARDWARE SETUP
# ===============================

i2c = busio.I2C(board.SCL, board.SDA)

# ---------- Button & LEDs (gpiozero-based) ----------
START_BTN = Button(20, pull_up=True, bounce_time=0.03)
GREEN_LED = LED(19)
RED_LED   = LED(13)
# ✅ Turn RED on as soon as the program starts
RED_LED.on()

# ---------- Ultrasonic sensor pins ----------
TRIG_FRONT, ECHO_FRONT = 22, 23  # GPIO pins for front sensor
TRIG_LEFT, ECHO_LEFT = 27, 17    # GPIO pins for left sensor
TRIG_RIGHT, ECHO_RIGHT = 5, 6    # GPIO pins for right sensor

# ---------- Motor ----------
MOTOR_FWD = 1                 # PCA9685 channel for forward motor control
MOTOR_REV = 2                 # PCA9685 channel for reverse motor control

# ---------- Servo ----------
SERVO_CHANNEL = 0             # PCA9685 channel controlling steering servo
SERVO_CENTER = 88              # Neutral servo angle (degrees)
SERVO_MIN_ANGLE = 50          # Minimum physical servo angle (degrees)
SERVO_MAX_ANGLE = 130         # Maximum physical servo angle (degrees)
SERVO_PULSE_MIN = 1000        # Minimum PWM pulse width (microseconds)
SERVO_PULSE_MAX = 2000        # Maximum PWM pulse width (microseconds)
SERVO_PERIOD = 20000          # Servo PWM period (microseconds)

# ===============================
# SENSOR INITIALIZATION (ToF + Ultrasonic)
# ===============================

vl53_left = vl53_right = vl53_front = vl53_back = None
vl53_front_left = vl53_front_right = None
us_left = us_right = us_front = None

try:
    # --------- ToF sensors ----------
    if USE_TOF_SIDES or USE_TOF_FRONT or USE_TOF_CORNERS:
        print("Initializing VL53L0X ToF sensors...")
        # XSHUT pins setup (for powering sensors individually)
        xshut_left  = digitalio.DigitalInOut(board.D16)
        xshut_right = digitalio.DigitalInOut(board.D25)
        xshut_front = digitalio.DigitalInOut(board.D26)
        xshut_back  = digitalio.DigitalInOut(board.D8)
        xshut_front_left  = digitalio.DigitalInOut(board.D7)
        xshut_front_right = digitalio.DigitalInOut(board.D24)
        for xshut in [xshut_left, xshut_right, xshut_front, xshut_back,
                      xshut_front_left, xshut_front_right]:
            xshut.direction = digitalio.Direction.OUTPUT
            xshut.value = False  # power down
        time.sleep(0.1)

        # Initialize left ToF if needed
        if USE_TOF_SIDES:
            xshut_left.value = True
            time.sleep(0.05)
            vl53_left = adafruit_vl53l0x.VL53L0X(i2c)
            vl53_left.set_address(0x30)
            vl53_left.measurement_timing_budget = 20000
            vl53_left.start_continuous()
            print("✅ Left ToF sensor set to address 0x30")

        # Initialize right ToF if needed
        if USE_TOF_SIDES:
            xshut_right.value = True
            time.sleep(0.05)
            vl53_right = adafruit_vl53l0x.VL53L0X(i2c)
            vl53_right.set_address(0x31)
            vl53_right.measurement_timing_budget = 20000
            vl53_right.start_continuous()
            print("✅ Right ToF sensor set to address 0x31")

        # Initialize front ToF if needed
        if USE_TOF_FRONT:
            xshut_front.value = True
            time.sleep(0.05)
            vl53_front = adafruit_vl53l0x.VL53L0X(i2c)
            vl53_front.set_address(0x32)
            vl53_front.measurement_timing_budget = 20000
            vl53_front.start_continuous()
            print("✅ Front ToF sensor set to address 0x32")
            
        # Initialize corner/front-left ToF (optional)
        if USE_TOF_CORNERS:
            xshut_front_left.value = True
            time.sleep(0.05)
            vl53_front_left = adafruit_vl53l0x.VL53L0X(i2c)
            vl53_front_left.set_address(0x34)
            vl53_front_left.measurement_timing_budget = 20000
            vl53_front_left.start_continuous()
            print("✅ Front-Left ToF sensor set to address 0x34")
            
        # Initialize corner/front-right ToF (optional)
        if USE_TOF_CORNERS:
            xshut_front_right.value = True
            time.sleep(0.05)
            vl53_front_right = adafruit_vl53l0x.VL53L0X(i2c)
            vl53_front_right.set_address(0x35)
            vl53_front_right.measurement_timing_budget = 20000
            vl53_front_right.start_continuous()
            print("✅ Front-Right ToF sensor set to address 0x35")

        # Initialize back ToF (optional, if you want to use it)
        xshut_back.value = True
        time.sleep(0.05)
        vl53_back = adafruit_vl53l0x.VL53L0X(i2c)
        vl53_back.set_address(0x33)
        vl53_back.measurement_timing_budget = 20000
        vl53_back.start_continuous()
        print("✅ Back ToF sensor set to address 0x33")

except Exception as e:
    print(f"[ERROR] VL53L0X initialization failed: {e}")
    # fallback to ultrasonic if ToF fails
    USE_TOF_SIDES = 0
    USE_TOF_FRONT = 0
    USE_TOF_CORNERS = 0
    vl53_left = vl53_right = vl53_front = vl53_back = None
    vl53_front_left = vl53_front_right = None

time.sleep(0.2)

# --------- Ultrasonic sensors ----------
# Initialize ultrasonic sensors only if that sensor is set to ultrasonic
if not USE_TOF_FRONT:
    us_front = DistanceSensor(echo=ECHO_FRONT, trigger=TRIG_FRONT, max_distance=US_MAX_DISTANCE_FRONT, queue_len=US_QUEUE_LEN)
if not USE_TOF_SIDES:
    us_left  = DistanceSensor(echo=ECHO_LEFT,  trigger=TRIG_LEFT,  max_distance=US_MAX_DISTANCE_SIDE, queue_len=US_QUEUE_LEN)
    us_right = DistanceSensor(echo=ECHO_RIGHT, trigger=TRIG_RIGHT, max_distance=US_MAX_DISTANCE_SIDE, queue_len=US_QUEUE_LEN)

dprint("Sensors initialized:")
dprint(f"  Front: {'ToF' if USE_TOF_FRONT else 'Ultrasonic'}")
dprint(f"  Left : {'ToF' if USE_TOF_SIDES else 'Ultrasonic'}")
dprint(f"  Right: {'ToF' if USE_TOF_SIDES else 'Ultrasonic'}")
if USE_TOF_CORNERS:
    dprint("  Turn corners: ToF (front_left & front_right)")

pca = PCA9685(i2c)
pca.frequency = 50
mpu = adafruit_mpu6050.MPU6050(i2c)

# ---------- Calibrate gyro bias at startup ----------
dprint("Calibrating gyro...")
N = 500
bias = 0
for _ in range(N):
    with I2C_LOCK:
        bias += mpu.gyro[2]
    time.sleep(0.005)
bias /= N
dprint(f"Gyro bias: {bias}")

# ===============================
# CONTROL FLAGS & STORAGE
# ===============================

STATE_SPEED = {
    "IDLE": SPEED_IDLE,
    "STOPPED": SPEED_STOPPED,
    "CRUISE": SPEED_CRUISE,
    "TURN_INIT": SPEED_TURN_INIT,
    "TURNING": SPEED_TURN,
    "POST_TURN": SPEED_POST_TURN
}

# ---------- CONTROL FLAGS ----------
readings_event = Event()
loop_event = Event()
sensor_tick = Event()   # used to wake waits immediately
shutdown_event = Event()
status_text = "Idle"
turn_count = 0
lap_count = 0
stop_reason = None # Reason-aware stopping (USER / OBSTACLE / LAPS)
obstacle_wait_deadline = 0.0
# --- Headless START button toggle / debounce ---
BTN_DEBOUNCE_S = 0.30   # seconds
_btn_prev = 1           # pull-up idle state (button not pressed)
_btn_last_ts = 0.0
paused_by_button = False

# ---------- SENSOR DATA STORAGE ----------
time_data = deque(maxlen=MAX_POINTS)
front_data = deque(maxlen=MAX_POINTS)
left_data = deque(maxlen=MAX_POINTS)
right_data = deque(maxlen=MAX_POINTS)
front_left_data  = deque(maxlen=MAX_POINTS)
front_right_data = deque(maxlen=MAX_POINTS)
angle_data = deque(maxlen=MAX_POINTS)
state_data = deque(maxlen=MAX_POINTS)

# ===============================
# THREADED SENSOR READING
# ===============================
sensor_data = {
    "front": None,
    "left": None,
    "right": None,
    "front_left": None,
    "front_right": None,
}
sensor_lock = threading.Lock()

# ===============================
# ROBOT CONTROLLER
# ===============================
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

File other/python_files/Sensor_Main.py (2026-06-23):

import time
from adafruit_servokit import ServoKit
import board
import busio
import digitalio
import adafruit_vl53l0x
from adafruit_as7341 import AS7341

# Setup I2C (shared communication line for sensors)
i2c = busio.I2C(board.SCL, board.SDA)

# Setup XSHUT pins for VL53L0X sensors
xshut_left = digitalio.DigitalInOut(board.D17)
xshut_right = digitalio.DigitalInOut(board.D27)
xshut_left.direction = digitalio.Direction.OUTPUT
xshut_right.direction = digitalio.Direction.OUTPUT

# Power down both TOF sensors
xshut_left.value = False
xshut_right.value = False
time.sleep(0.1)

# Power up left sensor and set its address
xshut_left.value = True
time.sleep(0.1)
sensor_left = adafruit_vl53l0x.VL53L0X(i2c)
sensor_left.set_address(0x30)

# Power up right sensor and set its address
xshut_right.value = True
time.sleep(0.1)
sensor_right = adafruit_vl53l0x.VL53L0X(i2c)
sensor_right.set_address(0x31)

# Initialize sensors with new addresses
sensor_left = adafruit_vl53l0x.VL53L0X(i2c, address=0x30)
sensor_right = adafruit_vl53l0x.VL53L0X(i2c, address=0x31)

# Color sensor
color_sensor = AS7341(i2c)

# Check if the color sensor is detected and initialized
if color_sensor:
    print("Color sensor initialized successfully.")
else:
    print("Color sensor initialization failed!")

# Turn on the sensor LED for better detection
color_sensor.led_current = 0
color_sensor.led = True

# Function to create a simple bar graph of the readings
def bar_graph(read_value):
    scaled = int(read_value / 1000)
    return "[%5d] " % read_value + (scaled * "*")

# ServoKit for motor control
kit = ServoKit(channels=8, i2c=i2c, address=0x40)

# ---------------- MOVEMENT FUNCTIONS ------------------
def turn_left(duration):
    print(f"Turning Left for {duration:.2f} sec")
    kit.servo[0].angle = 70
    kit.continuous_servo[1].throttle = 1
    time.sleep(duration)
    kit.continuous_servo[1].throttle = 0

def turn_right(duration):
    print(f"Turning Right for {duration:.2f} sec")
    kit.servo[0].angle = 130
    kit.continuous_servo[1].throttle = 1
    time.sleep(duration)
    kit.continuous_servo[1].throttle = 0

# ---------------- MAIN LOOP ------------------
try:
    time.sleep(1)

    # Get initial distances from TOF sensors
    left = sensor_left.range / 10  # mm to cm
    right = sensor_right.range / 10

    if left > right:
        reference_side = "left"
        waiting_for = "right"
    else:
        reference_side = "right"
        waiting_for = "left"

    print(f"Reference: {reference_side}, waiting for '{waiting_for}' to reach 5 cm.")

    # Detection and tracking
    at_target_position = False
    locked_color = None
    total_detections = 0
    blue_count = 0
    orange_count = 0
    motor_time = 1.5

    # Color detection thresholds
    blue_threshold = 900
    orange_threshold = 900
    color_margin = 100

    while total_detections < 12:
        # Read TOF distances
        left_distance = sensor_left.range / 10
        right_distance = sensor_right.range / 10
        distance_diff = abs(left_distance - right_distance)

        # Read relevant color sensor channels (in lux or detected light levels)
        blue = color_sensor.channel_480nm or 0
        orange = color_sensor.channel_630nm or 0

        # Debugging the color sensor readings
        print(f"Color Sensor Readings → 480nm (Blue): {blue} | 630nm (Orange): {orange}")

        # Bar graph for color readings
        print("F3 - 480nm//Blue   %s" % bar_graph(blue))
        print("F7 - 630nm/Orange  %s" % bar_graph(orange))

        # Decision logic variables
        turn_decision = None
        color_detected = None

        print("\n--- Iteration Report --------------------------------------")
        print(f"TOF Distances → Left: {left_distance:.1f} cm | Right: {right_distance:.1f} cm")
        print(f"Distance Difference: {distance_diff:.1f} cm")
        
        if blue > orange and blue > blue_threshold and (blue - orange > color_margin):
            if locked_color != "blue":
                locked_color = "blue"
                print("🔵 Color Lock Updated → BLUE")
            color_detected = "blue"
            turn_decision = "right"
            print("Action: Blue detected! Turning RIGHT.")
            turn_right(motor_time)
            blue_count += 1
            total_detections += 1

        elif orange > blue and orange > orange_threshold and (orange - blue > color_margin):
            if locked_color != "orange":
                locked_color = "orange"
                print("Color Lock Updated → ORANGE")
            color_detected = "orange"
            turn_decision = "left"
            print("Action: Orange detected! Turning LEFT.")
            turn_left(motor_time)
            orange_count += 1
            total_detections += 1

        else:
            # No strong color detected; fallback to TOF decision
            if left_distance > right_distance:
                turn_decision = "right"
                print("No color lock. Based on TOF → Turning RIGHT.")
                turn_right(motor_time)
            else:
                turn_decision = "left"
                print("No color lock. Based on TOF → Turning LEFT.")
                turn_left(motor_time)

        # Position tracking
        if not at_target_position:
            print(f"Target Check → Waiting for '{waiting_for}' to reach ≤ 5 cm.")
            if (waiting_for == "left" and left_distance <= 5) or (waiting_for == "right" and right_distance <= 5):
                print("Target position reached!")
                kit.continuous_servo[1].throttle = 0
                at_target_position = True
            else:
                print("Moving forward toward target...")
                kit.continuous_servo[1].throttle = 0.5
                time.sleep(0.5)
                kit.continuous_servo[1].throttle = 0
        else:
            print("Holding position. Monitoring for color...")

        print(f"Servo Angle: {kit.servo[0].angle if kit.servo[0].angle else 'N/A'}")
        print(f"Motor Throttle: {kit.continuous_servo[1].throttle}")
        print(f"Status → Blue: {blue_count}, Orange: {orange_count}, Total: {total_detections}")
        print("--------------------------------------------------------------")
        time.sleep(1)

    print("12 detections complete. Shutting down.")

except KeyboardInterrupt:
    print("Program interrupted by user.")

finally:
    kit.continuous_servo[1].throttle = 0
    print("Motors off. Program ended.")

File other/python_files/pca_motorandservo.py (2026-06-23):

import time
import RPi.GPIO as GPIO
from board import SCL, SDA
import busio
from adafruit_pca9685 import PCA9685

# --- Global State ---
turns_completed = 0
direction = "left"  # default direction

# --- PCA9685 Setup ---
i2c = busio.I2C(SCL, SDA)
pca = PCA9685(i2c)
pca.frequency = 50  # Default for servos

# --- PID Constants ---
TARGET_DISTANCE = 20.0  # cm
KP = 0.8
KI = 0.0
KD = 2.3

integral = 0
last_error = 0
SERVO_CHANNEL = 0

# --- GPIO Setup ---
GPIO.setmode(GPIO.BCM)

TRIG_1, ECHO_1 = 22, 23   # Front sensor
TRIG_2, ECHO_2 = 5, 6     # Left sensor
TRIG_3, ECHO_3 = 27, 17   # Right sensor

for trig in [TRIG_1, TRIG_2, TRIG_3]:
    GPIO.setup(trig, GPIO.OUT)
    GPIO.output(trig, GPIO.LOW)

for echo in [ECHO_1, ECHO_2, ECHO_3]:
    GPIO.setup(echo, GPIO.IN)

# --- Motor Channels ---
MOTOR_FWD = 1
MOTOR_REV = 0

# --- Motor Control ---
def rotate_motor_forward():
    speed = 80
    duty_cycle = int(min(max(abs(speed), 0), 100) / 100 * 65535)
    pca.channels[MOTOR_FWD].duty_cycle = duty_cycle
    pca.channels[MOTOR_REV].duty_cycle = 0

def rotate_motor_backward():
    speed = -50
    duty_cycle = int(min(max(abs(speed), 0), 100) / 100 * 65535)
    pca.channels[MOTOR_FWD].duty_cycle = 0
    pca.channels[MOTOR_REV].duty_cycle = duty_cycle

def stop_motor():
    pca.channels[MOTOR_FWD].duty_cycle = 0
    pca.channels[MOTOR_REV].duty_cycle = 0

# --- Distance Measurement ---
def get_distance(trigger_pin, echo_pin):
    GPIO.output(trigger_pin, GPIO.HIGH)
    time.sleep(0.00001)  # 10 µs pulse
    GPIO.output(trigger_pin, GPIO.LOW)

    pulse_start, pulse_end = None, None

    # Wait for echo to start
    timeout = time.time() + 0.02
    while GPIO.input(echo_pin) == GPIO.LOW:
        pulse_start = time.time()
        if pulse_start > timeout:
            return None

    # Wait for echo to end
    timeout = time.time() + 0.02
    while GPIO.input(echo_pin) == GPIO.HIGH:
        pulse_end = time.time()
        if pulse_end > timeout:
            return None

    if pulse_start and pulse_end:
        pulse_duration = pulse_end - pulse_start
        return (pulse_duration * 34300) / 2  # cm

    return None

# --- Main Loop ---
try:
    while True:
        distance_front = get_distance(TRIG_1, ECHO_1)
        distance_left = get_distance(TRIG_2, ECHO_2)
        distance_right = get_distance(TRIG_3, ECHO_3)

        if direction == "left":
            side_sensor = distance_left
        else:
            side_sensor = distance_right

        rotate_motor_forward()

        if side_sensor is None:
            print("Sensor error, skipping cycle.")
            continue

        # Detect wall loss
        if side_sensor > 100 and distance_front and distance_front < 120:
            if direction == "left":
                print("Wall lost! Sharp LEFT turn")
                set_servo_angle(SERVO_CHANNEL, 40)
                if distance_right and distance_right > 100:
                    set_servo_angle(SERVO_CHANNEL, 110)
            else:
                print("Wall lost! Sharp RIGHT turn")
                set_servo_angle(SERVO_CHANNEL, 135)

            turns_completed += 1
            print(f"Turns completed: {turns_completed}")
            time.sleep(0.1)
            continue

        # --- PID Control ---
        error = TARGET_DISTANCE - side_sensor
        integral += error
        derivative = error - last_error
        output = KP * error + KI * integral + KD * derivative

        # Use servo min/max 50/130
        if direction == "left":
            new_angle = max(50, min(130, 90 + output))
        else:
            new_angle = max(50, min(130, 90 - output))  # mirrored for right wall

        # Direct servo control using adafruit_pca9685
        min_angle = 50
        max_angle = 130
        angle = max(min_angle, min(max_angle, new_angle))
        pulse_min = 1000  # 1ms
        pulse_max = 2000  # 2ms
        pulse = int(pulse_min + (pulse_max - pulse_min) * ((angle - min_angle) / (max_angle - min_angle)))
        pca.channels[SERVO_CHANNEL].duty_cycle = int(pulse * 65535 / 20000)  # 20ms period

        print(f"Side: {side_sensor:.1f} cm | Error: {error:.2f} | Servo: {new_angle:.1f}")
        print(f"Turns completed: {turns_completed}")

        last_error = error
        time.sleep(0.1)

except KeyboardInterrupt:
    print("Stopping safely...")
    stop_motor()
    GPIO.cleanup()

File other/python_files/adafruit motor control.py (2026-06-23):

import time
from adafruit_motorkit import MotorKit

# Initialize the motor kit (this automatically detects the connected I2C motor shield)
kit = MotorKit()

# Function to rotate the motor forward
def rotate_motor_forward():
    print("Rotating motor forward")
    kit.motor3.throttle = 1.0  # Full speed forward

# Function to rotate the motor backward
def rotate_motor_backward():
    print("Rotating motor backward")
    kit.motor3.throttle = -1.0  # Full speed backward

# Function to stop the motor
def stop_motor():
    print("Stopping motor")
    kit.motor3.throttle = 0.0  # Stop the motor

# Main program loop to test motor control
try:
    # Rotate the motor forward for 3 seconds
    rotate_motor_forward()
    time.sleep(3)

    # Rotate the motor backward for 3 seconds
    rotate_motor_backward()
    time.sleep(3)

    # Stop the motor
    stop_motor()

finally:
    stop_motor()  # Ensure motor stops when program ends

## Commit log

2026-06-23 Update print statement from 'Hello' to 'Goodbye'
2026-06-25 Revise equipment and materials links in manual
    Updated links in the instruction manual to remove specific URLs.
2026-06-25 Add LEGO Ackermann instructions document
    Added instructions for recreating the LEGO Ackermann steering system on a robot car, including parts needed and links to additional resources.
2026-06-25 Add LEGO differential assembly instructions
    Added detailed instructions for assembling the LEGO differential system, including parts needed and step-by-step guidance with images.
2026-06-25 Add materials needed and BOM documentation
    This document lists the materials needed for the project along with their amounts and prices in Euros.
2026-06-25 Fix link to equipment and materials in manual
    Updated the link for necessary equipment and materials in the instruction manual.
2026-06-25 Update instruction manual with correct Lego links
    Updated links for Lego Ackerman instructions and clarified the importance of having all necessary materials before proceeding.
2026-06-26 Add link to camera base STL in models readme
2026-06-26 Update readme with 3D print design details
    Added download links for 3D print designs and a software recommendation.
2026-06-26 Revise 3D print design file descriptions
    Updated the readme to improve clarity and organization of the 3D print design files.
2026-06-26 Rename Materials needed and BOM.md to Materials_needed_and_BOM.md
2026-06-26 Revise README with component details and images
    Updated the README to provide detailed descriptions of mechanical components, PCB photos, and layout.
2026-06-27 Fix file paths in readme for 3D designs and instructions
    Updated file paths for 3D print designs and assembly instructions to reflect new directory structure.
2026-06-27 Revise README for LEGO assembly instructions
    Updated the README to clarify LEGO pieces needed for the differential gear and Ackermann steering system, and revised links to assembly instructions.
2026-06-27 Update README to include assembly manuals
2026-06-27 Update PCB image references in README.md
    Replaced image links with HTML img tags for better formatting.
2026-06-27 Enhance README with DC Drive Motor details
    Added detailed specifications, integration notes, and alternative motor options for the DC Drive Motor in the README.
2026-06-27 Add README for ArduCam IMX219 camera module
    Added detailed information about the ArduCam IMX219 camera module, including its characteristics, compatibility, and alternatives.
2026-06-27 Add image to ArduCam IMX219 README
    Added an image to the README for the ArduCam IMX219 camera.
2026-06-27 Rename Screenshot 2026-06-27 133012.png to PCB_2D.png
2026-06-27 Rename Screenshot 2026-06-27 133540.png to PCB_3D_front.png
2026-06-27 Rename Screenshot 2026-06-27 133620.png to PCB_3D_back.png
